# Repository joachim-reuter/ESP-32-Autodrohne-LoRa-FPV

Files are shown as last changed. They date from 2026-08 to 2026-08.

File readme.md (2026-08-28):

# ESP32 Autodrohne – LoRa-Steuerung und FPV

Ein selbstgebautes, drahtlos gesteuertes Fahrzeug auf Basis von ESP32.

Die Steuerung erfolgt über **LoRa mit 433 MHz**. Das Fahrzeug besitzt vier Antriebsmotoren, die über zwei Motorgruppen gesteuert werden. Ein Trackball im Steuerpult ermöglicht die proportionale Steuerung von Fahrtrichtung und Geschwindigkeit.

Zusätzlich ist auf dem Fahrzeug eine **FPV-Kamera** installiert. Das Kamerabild wird über eine separate **5,8-GHz-Funkverbindung** an einen FPV-Monitor übertragen, der direkt in das Steuerpult integriert ist.

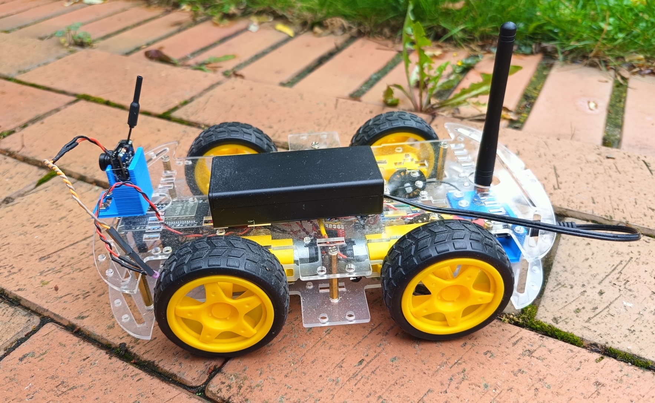
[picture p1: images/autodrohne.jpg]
Autodrohne


---

## Projektübersicht

Das System besteht aus zwei voneinander getrennten Funkverbindungen.

```text
                         STEUERPULT
┌──────────────────────────────────────────────────┐
│                                                  │
│   ESP32-Steuerung                                │
│                                                  │
│   Trackball       Drehencoder       OLED         │
│      │                │               │          │
│      └────────────────┴───────────────┘          │
│                       │                          │
│                    LoRa 433 MHz                  │
│                       │                          │
│   ┌──────────────────────────────────────────┐   │
│   │          FPV-Monitor                     │   │
│   │          5,8-GHz-Empfänger               │   │
│   └──────────────────────────────────────────┘   │
│                                                  │
└──────────────────────┬───────────────────────────┘
                       │
                       │ LoRa 433 MHz
                       │ Steuerdaten
                       ▼
              ┌──────────────────┐
              │      AUTO        │
              │                  │
              │      ESP32       │
              │      LoRa        │
              │      DRV8833     │
              │      4 Motoren   │
              │                  │
              │   FPV-Kamera     │
              └────────┬─────────┘
                       │
                       │ 5,8 GHz
                       │ Video
                       ▼
                  FPV-Empfänger
                  im Steuerpult
```

---

# Funkverbindungen

Das Fahrzeug verwendet zwei voneinander getrennte Funkstrecken.

| System | Frequenz | Funktion |
| --- | ---: | --- |
| LoRa |  433 MHz | Fahrzeugsteuerung |
| FPV |  5,8 GHz | Live-Videobild |

Die LoRa-Verbindung wird ausschließlich für die Steuerdaten und die Rückmeldung der Signalstärke verwendet.

Die FPV-Verbindung überträgt das Kamerabild unabhängig von der Fahrzeugsteuerung.

---

# Steuerung

Die Steuerung erfolgt über einen analogen Trackball.

Der Trackball ermöglicht eine proportionale Steuerung:

* Vorwärts
* Rückwärts
* Links
* Rechts

Die beiden Achsen des Trackballs werden zunächst kalibriert.

Um kleine Schwankungen um die Mittelstellung zu unterdrücken, wird eine Totzone verwendet:

```cpp
#define DEADZONE 120
```

Damit bleibt das Fahrzeug bei nicht betätigtem Trackball stehen.

---

# Geschwindigkeitsregelung

Die maximale Geschwindigkeit wird über einen Drehencoder eingestellt.

Der Einstellbereich beträgt:

```text
0–100 %
```

Der aktuelle Geschwindigkeitswert wird auf dem OLED angezeigt.

Die eigentliche Motorleistung wird anschließend auf den PWM-Bereich des Motortreibers umgesetzt.

---

# OLED-Anzeige

Im Steuerpult befindet sich ein 128 × 64 Pixel OLED.

Angezeigt werden:

* Geschwindigkeit
* Vorwärts-/Rückwärtswert
* Links-/Rechtswert
* LoRa-RSSI
* grafische Anzeige der Funkqualität

Beispiel:

```text
SPD 50%

FB: 20
LR: -10

-65 dBm       RSSI
```

Damit kann während der Fahrt sowohl die aktuelle Steuerung als auch die Qualität der LoRa-Verbindung beobachtet werden.

---

# LoRa-Steuertelegramm

Der Handsender überträgt die Steuerdaten als Texttelegramm.

Format:

```text
DRV,FB,LR,SPEED
```

Beispiel:

```text
DRV,50,-20,70
```

Bedeutung:

| Wert  | Bedeutung |
| ----- | --- |
| `DRV` | Steuertelegramm |
| `50`  | Vorwärts-/Rückwärtswert |
| `-20` | Links-/Rechtswert |
| `70`  | Geschwindigkeit 70 % |

---

# Motorsteuerung

Das Fahrzeug besitzt zwei unabhängig angesteuerte Motorgruppen.

```text
             ESP32
               │
               ▼
            DRV8833
          ┌─────┴─────┐
          │           │
          ▼           ▼
     linke Seite   rechte Seite
     2 Motoren     2 Motoren
```

Die beiden Motorgruppen werden unterschiedlich angesteuert, um das Fahrzeug zu lenken.

Die Motorwerte werden aus Fahr- und Lenkwert berechnet:

```cpp
left  = fb + lr;
right = fb - lr;
```

Die Werte werden anschließend begrenzt und entsprechend der eingestellten Geschwindigkeit auf die PWM-Ausgänge umgesetzt.

---

# Motoranschlüsse

## Linke Motorgruppe

| ESP32 | Funktion |
| --- | --- |
| GPIO 25 | PWM |
| GPIO 27 | IN1 |
| GPIO 14 | IN2 |

## Rechte Motorgruppe

| ESP32 | Funktion |
| --- | --- |
| GPIO 33 | PWM |
| GPIO 12 | IN1 |
| GPIO 13 | IN2 |

## DRV8833

| ESP32 | Funktion |
| --- | --- |
| GPIO 32 | STBY |

---

# LoRa-Anschluss

Für das LoRa-Modul werden folgende SPI-Pins verwendet:

| ESP32 | Funktion |
| --- | --- |
| GPIO 18 | SCK |
| GPIO 19 | MISO |
| GPIO 23 | MOSI |
| GPIO 5  | SS / CS  |
| GPIO 26 | DIO0 |

### Fahrzeug

Beim Fahrzeug wird kein separater Reset-Pin verwendet:

```cpp
#define LORA_RST -1
```

### Handsender

Beim Handsender wird GPIO 17 für Reset verwendet:

```cpp
#define LORA_RST 17
```

---

# ACK und RSSI

Nach dem Empfang eines gültigen Steuertelegramms sendet das Fahrzeug eine kurze Rückmeldung:

```text
ACK
```

Der Handsender empfängt diese Rückmeldung und ermittelt daraus die empfangene LoRa-Signalstärke.

Der RSSI-Wert wird anschließend auf dem OLED angezeigt.

Dadurch lässt sich die Funkverbindung während der Fahrt beobachten.

---

# Failsafe

Das Fahrzeug besitzt eine automatische Sicherheitsabschaltung.

Wenn länger als

```text
400 ms
```

kein gültiges Steuertelegramm empfangen wird, werden die Motoren gestoppt.

Zusätzlich wird der Standby-Eingang des DRV8833 deaktiviert.

```cpp
#define FAILSAFE_MS 400
```

Der Failsafe verhindert damit, dass das Fahrzeug bei einem Ausfall oder Abbruch der LoRa-Verbindung unkontrolliert weiterfährt.

---

# FPV-System

Die FPV-Kamera ist direkt auf dem Fahrzeug montiert.

Das Kamerabild wird über eine separate **5,8-GHz-Funkverbindung** übertragen.

Der zugehörige FPV-Empfänger befindet sich im Steuerpult und ist mit einem Monitor verbunden.

```text
FPV-Kamera
     │
     │ 5,8 GHz
     ▼
FPV-Empfänger
     │
     ▼
Monitor im Steuerpult
```

Dadurch kann das Fahrzeug über das Livebild der Kamera gesteuert werden.

Die FPV-Übertragung ist unabhängig von der LoRa-Steuerung.

---

# Steuerpult

Das Steuerpult vereint die komplette Bedienung:

* ESP32
* LoRa-Sender
* Trackball
* Drehencoder
* OLED
* 5,8-GHz-FPV-Empfänger
* FPV-Monitor

Damit befinden sich Fahrzeugsteuerung und Kamerabild in einer gemeinsamen Bedieneinheit.

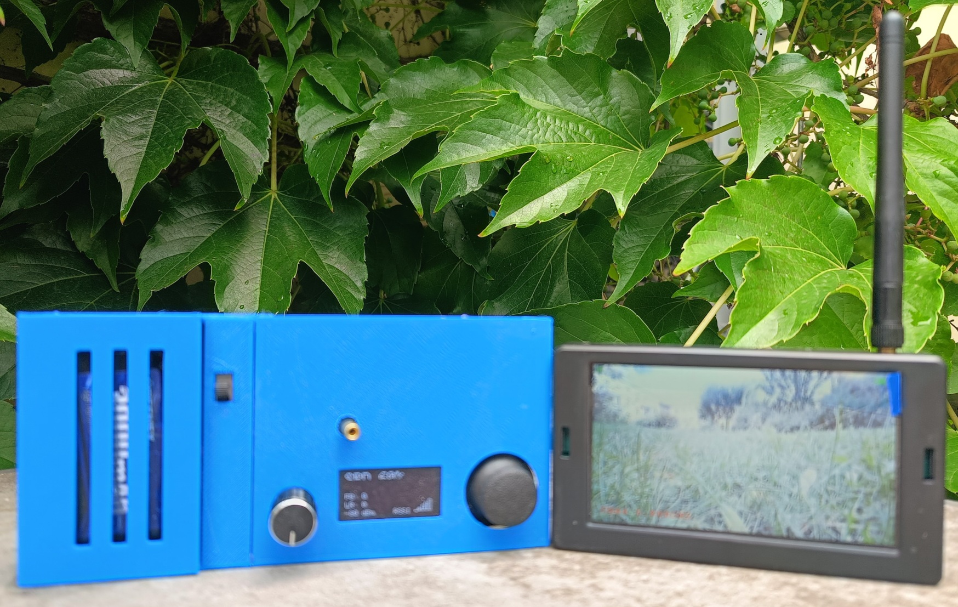
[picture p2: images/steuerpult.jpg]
Steuerpult


---

# Hardware

## Fahrzeug

* ESP32
* LoRa-Modul
* DRV8833
* 4 Gleichstrommotoren
* FPV-Kamera
* 5,8-GHz-Videosender
* Fahrzeugakku

## Steuerpult

* ESP32
* LoRa-Modul
* analoger Trackball
* Drehencoder
* 128 × 64 OLED
* 5,8-GHz-FPV-Empfänger
* FPV-Monitor

---

# Handsender – Anschlüsse

## Trackball

| ESP32 | Funktion |
| --- | --- |
| GPIO 34 | X-Achse  |
| GPIO 35 | Y-Achse  |

## Drehencoder

| ESP32 | Funktion |
| --- | --- |
| GPIO 27 | CLK |
| GPIO 14 | DT |
| GPIO 32 | Taster |

## OLED

Das OLED wird über I²C angeschlossen:

| ESP32 | Funktion |
| --- | --- |
| GPIO 21 | SDA |
| GPIO 22 | SCL |

I²C-Adresse:

```text
0x3C
```

---

# Software

## Fahrzeug

Der Fahrzeug-Empfänger verwendet:

```cpp
#include <SPI.h>
#include <LoRa.h>
```

## Handsender

Der Handsender verwendet:

```cpp
#include <SPI.h>
#include <LoRa.h>
#include <Wire.h>
#include <Adafruit_GFX.h>
#include <Adafruit_SH110X.h>
```

---

# Dateien

Das Repository enthält die beiden Hauptbereiche:

```text
ESP32-Autodrohne-LoRa-FPV/
│
├── README.md
│
├── _AutoDrohne_Empfaenger.ino
├── _AutoDrohne_Sender.ino
│
└── images/
    ├── autodrohne.jpg
    └── steuerpult.jpg
```

Die Dateinamen können entsprechend den tatsächlich im Repository verwendeten Namen angepasst werden.

---

# Systemaufbau

```text
┌──────────────────────┐
│      STEUERPULT      │
│                      │
│ ESP32                │
│ Trackball            │
│ Drehencoder          │
│ OLED                 │
│ LoRa                 │
│ FPV Monitor          │
│ 5,8 GHz Empfänger    │
└──────────┬───────────┘
           │
           │ 433 MHz
           │ Steuerdaten
           ▼
┌──────────────────────┐
│        AUTO          │
│                      │
│ ESP32                │
│ LoRa                 │
│ DRV8833              │
│ 4 Motoren            │
│ FPV Kamera           │
│ 5,8 GHz Sender       │
└──────────────────────┘
```

---

# Projektstatus

Das Projekt befindet sich in Entwicklung.

Die LoRa-Fahrzeugsteuerung mit:

* Trackball
* Geschwindigkeitsregelung
* OLED-Anzeige
* RSSI-Anzeige
* ACK-Rückmeldung
* Failsafe
* Zweimotorgruppensteuerung

ist als funktionierender Entwicklungsstand vorhanden.

Die FPV-Kamera und die 5,8-GHz-Videoübertragung sind als separates Videosystem in das Fahrzeug und das Steuerpult integriert.

---

# Mögliche Erweiterungen

Das System bietet verschiedene Möglichkeiten zur Erweiterung:

* Akkuspannungsanzeige
* Telemetrie
* Entfernungsmessung
* weitere Sensoren
* Beleuchtung
* Bremslicht
* Hupe/Sound
* Kameraschwenkung
* zusätzliche FPV-Funktionen
* weitere Fahrzeugfunktionen
* Verbesserung der Reichweiten- und Signalüberwachung

---

# Autor

**Joachim Reuter**

Privates ESP32-, LoRa-, FPV- und Modellbauprojekt.

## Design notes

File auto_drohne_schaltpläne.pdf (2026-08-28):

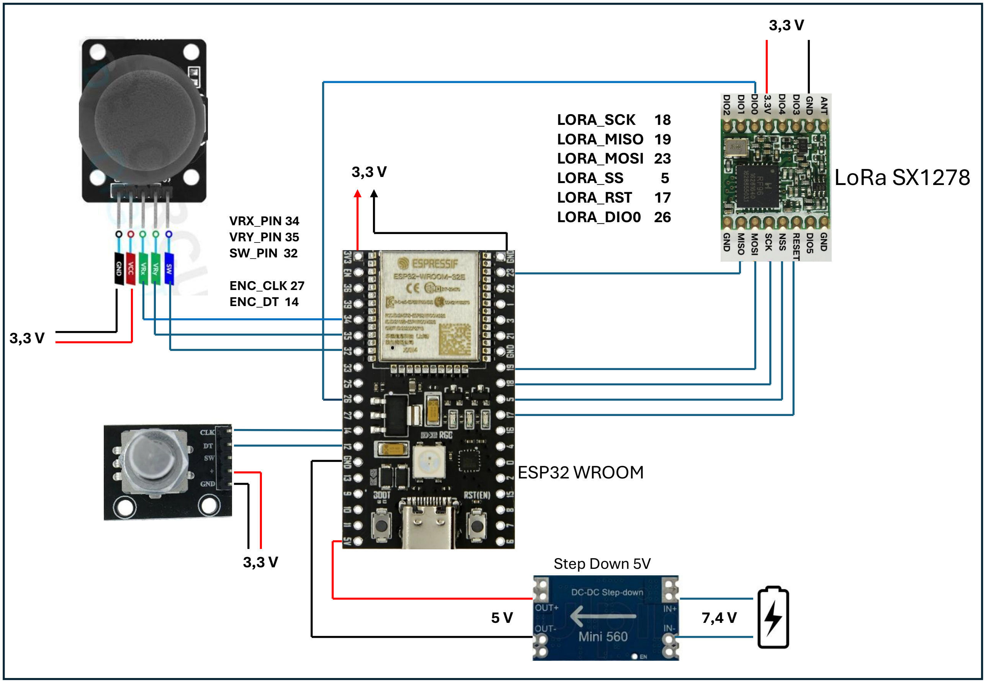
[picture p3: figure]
LORA_SCK 18 LORA_MISO 19 LORA_MOSI 23; LORA_SS; LORA_RST 17 LORA_DIO0 26; ESP32 WROOM; LoRa SX1278; VRX_PIN 34 VRY_PIN 35 SW_PIN 32; ENC_CLK 27 ENC_DT 14; Step Down 5V

3,3 V

LORA_SCK 18
LORA_MISO 19
LORA_MOSI 23
LORA_SS 5
LORA_RST 17
LORA_DIO0 26

## ESP32 WROOM

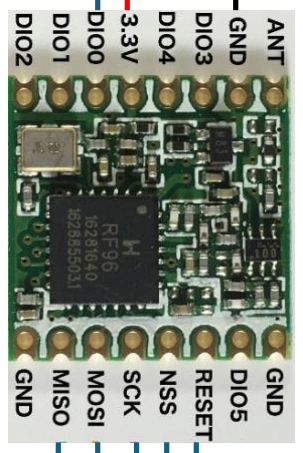
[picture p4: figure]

## LoRa SX1278

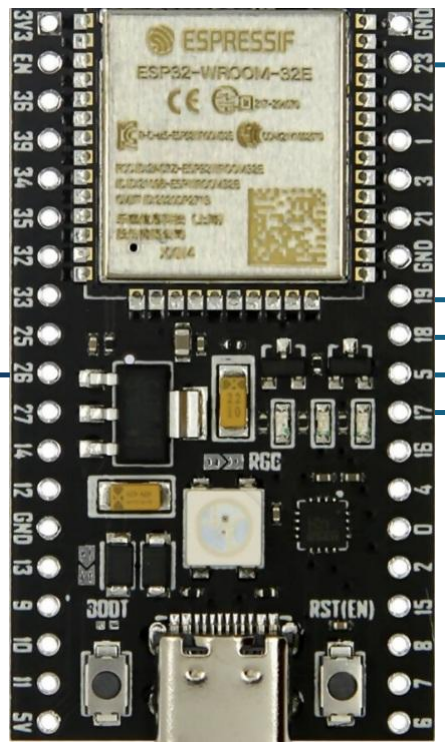
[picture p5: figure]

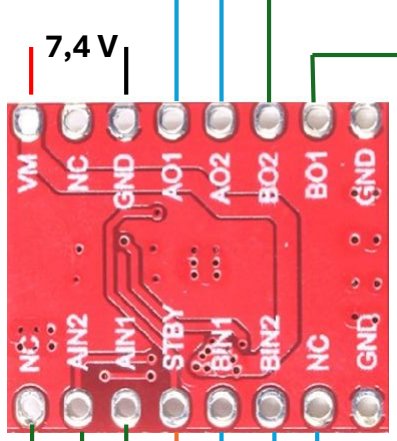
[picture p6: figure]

## DRV8833

## ESP32 WROOM

Antriebsmotoren links

M1_PWM 25
M1_IN1 27
M1_IN2 14

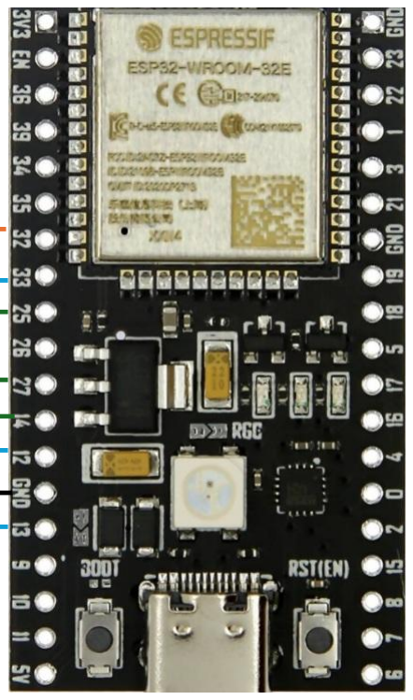
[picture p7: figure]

M2_PWM 33
M2_IN1 12
M2_IN2 13

DRV_STBY 32

Antriebsmotoren rechts

Step Down 5V

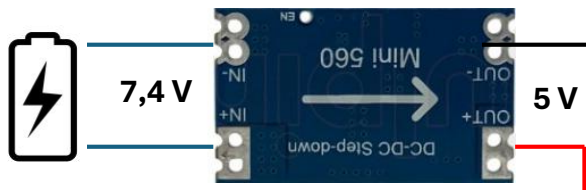
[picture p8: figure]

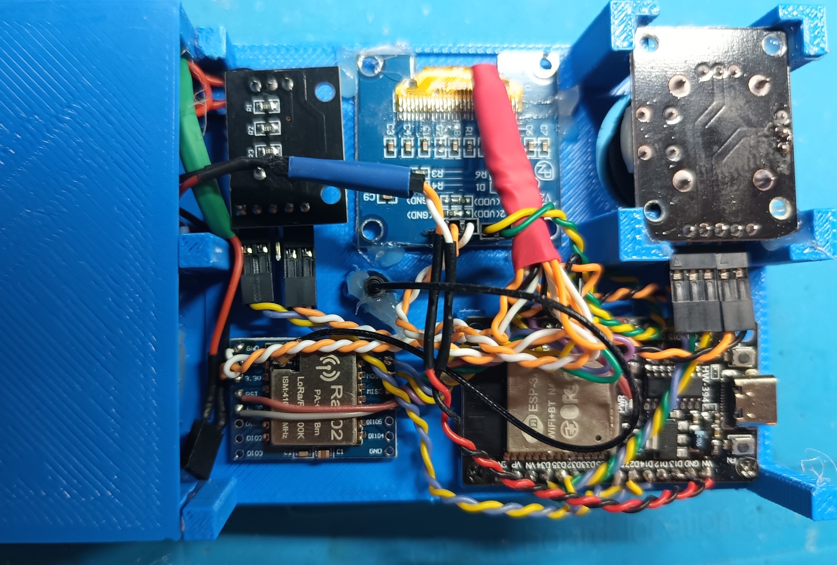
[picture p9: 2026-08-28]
images/pult_innen.jpg

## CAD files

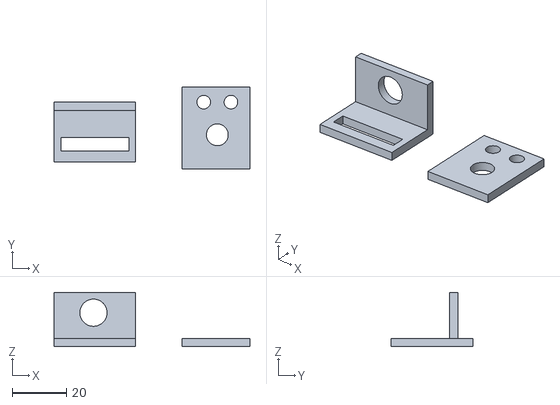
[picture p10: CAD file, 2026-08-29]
3D_print/Auto_Kabel_V1.stl
72.0 x 30.0 x 20.0

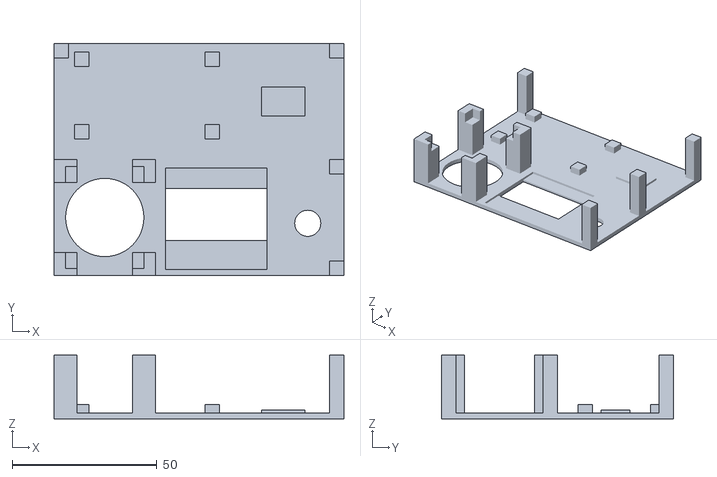
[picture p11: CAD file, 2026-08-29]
3D_print/Auto_Gehäuse_V2.stl
100.0 x 80.0 x 22.0

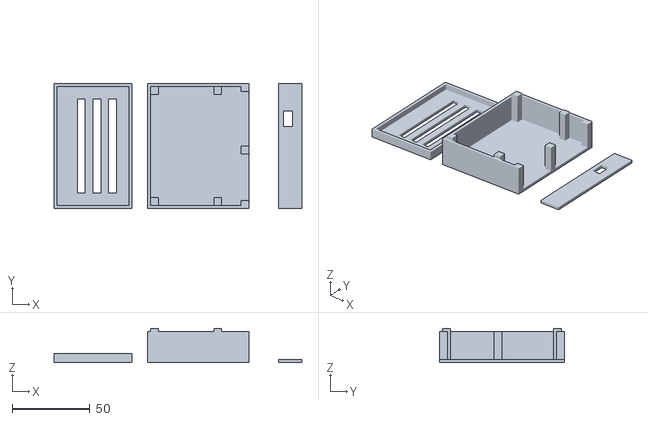
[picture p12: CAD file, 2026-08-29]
3D_print/Auto_Akku_Halter_V1.stl
159.0 x 80.0 x 22.0

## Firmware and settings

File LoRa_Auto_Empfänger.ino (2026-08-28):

#include <SPI.h>
#include <LoRa.h>

// ================= LoRa =================
#define LORA_SCK   18
#define LORA_MISO  19
#define LORA_MOSI  23
#define LORA_SS     5
#define LORA_RST   -1
#define LORA_DIO0  26

// ================= DRV8833 =================
// Linke Seite (2 Motoren parallel)
#define M1_PWM 25
#define M1_IN1 27
#define M1_IN2 14

// Rechte Seite (2 Motoren parallel)
#define M2_PWM 33
#define M2_IN1 12
#define M2_IN2 13

#define DRV_STBY 32

// ================= Failsafe =================
unsigned long lastPacket = 0;
const unsigned long FAILSAFE_MS = 400;

// ================= Motor =================
void setMotor(int pwmPin, int in1, int in2, int value) {
  value = constrain(value, -255, 255);

  if (value > 0) {
    digitalWrite(in1, HIGH);
    digitalWrite(in2, LOW);
    analogWrite(pwmPin, value);
  }
  else if (value < 0) {
    digitalWrite(in1, LOW);
    digitalWrite(in2, HIGH);
    analogWrite(pwmPin, -value);
  }
  else {
    digitalWrite(in1, LOW);
    digitalWrite(in2, LOW);
    analogWrite(pwmPin, 0);
  }
}

void stopMotors() {
  analogWrite(M1_PWM, 0);
  analogWrite(M2_PWM, 0);

  digitalWrite(M1_IN1, LOW);
  digitalWrite(M1_IN2, LOW);
  digitalWrite(M2_IN1, LOW);
  digitalWrite(M2_IN2, LOW);
}

// ================= Setup =================
void setup() {
  Serial.begin(115200);
  Serial.println("🚗 LoRa EMPFÄNGER gestartet");

  pinMode(M1_PWM, OUTPUT);
  pinMode(M1_IN1, OUTPUT);
  pinMode(M1_IN2, OUTPUT);

  pinMode(M2_PWM, OUTPUT);
  pinMode(M2_IN1, OUTPUT);
  pinMode(M2_IN2, OUTPUT);

  pinMode(DRV_STBY, OUTPUT);
  digitalWrite(DRV_STBY, HIGH);

  stopMotors();

  SPI.begin(LORA_SCK, LORA_MISO, LORA_MOSI, LORA_SS);
  LoRa.setPins(LORA_SS, LORA_RST, LORA_DIO0);

  if (!LoRa.begin(433E6)) {
    Serial.println("❌ LoRa Fehler");
    while (1);
  }

  Serial.println("✅ LoRa bereit");
}

// ================= Loop =================
void loop() {
  int packetSize = LoRa.parsePacket();

  if (packetSize) {
    String msg = LoRa.readString();
    msg.trim();
    lastPacket = millis();

    int fb, lr, speed;
    if (sscanf(msg.c_str(), "DRV,%d,%d,%d", &fb, &lr, &speed) == 3) {

      // --- Mischen ---
      int left  = fb + lr;
      int right = fb - lr;

      left  = constrain(left,  -100, 100);
      right = constrain(right, -100, 100);

      int maxPWM = map(speed, 0, 100, 0, 255);

      left  = left  * maxPWM / 100;
      right = right * maxPWM / 100;

      setMotor(M1_PWM, M1_IN1, M1_IN2, left);
      setMotor(M2_PWM, M2_IN1, M2_IN2, right);

      // ACK (optional für RSSI)
      LoRa.beginPacket();
      LoRa.print("ACK");
      LoRa.endPacket();
    }
  }

  // ================= Failsafe =================
  if (millis() - lastPacket > FAILSAFE_MS) {
    stopMotors();
    digitalWrite(DRV_STBY, LOW);
  } else {
    digitalWrite(DRV_STBY, HIGH);
  }
}

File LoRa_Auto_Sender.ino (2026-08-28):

#include <SPI.h>
#include <LoRa.h>
#include <Wire.h>
#include <Adafruit_GFX.h>
#include <Adafruit_SH110X.h>

// ========== OLED ==========
Adafruit_SH1106G display(128, 64, &Wire, -1);

// ========== Trackball ==========
#define VRX_PIN 34
#define VRY_PIN 35

// ========== Encoder ==========
#define ENC_CLK 27
#define ENC_DT  14
#define ENC_SW  32

volatile int speed = 50;
portMUX_TYPE mux = portMUX_INITIALIZER_UNLOCKED;

// ========== LoRa ==========
#define LORA_SCK   18
#define LORA_MISO  19
#define LORA_MOSI  23
#define LORA_SS     5
#define LORA_RST   17
#define LORA_DIO0  26

int lastRSSI = -120;

// ========== Trackball Kalibrierung ==========
int xCenter = 0;
int yCenter = 0;
#define DEADZONE 120

// ---------- Encoder ISR ----------
void IRAM_ATTR encoderISR() {
  portENTER_CRITICAL_ISR(&mux);
  if (digitalRead(ENC_DT)) speed++;
  else speed--;
  speed = constrain(speed, 0, 100);
  portEXIT_CRITICAL_ISR(&mux);
}

// ---------- Trackball Mapping ----------
int mapAxis(int raw, int center) {
  if (abs(raw - center) < DEADZONE) return 0;

  if (raw > center) {
    return map(raw, center + DEADZONE, 4095, 0, 100);
  } else {
    return map(raw, 0, center - DEADZONE, -100, 0);
  }
}

// ---------- Kalibrierung ----------
void calibrateCenter() {
  long sx = 0, sy = 0;
  for (int i = 0; i < 50; i++) {
    sx += analogRead(VRX_PIN);
    sy += analogRead(VRY_PIN);
    delay(5);
  }
  xCenter = sx / 50;
  yCenter = sy / 50;
}

// ---------- RSSI Balken ----------
void drawRSSIBar(int rssi) {
  int bars = map(rssi, -120, -40, 0, 5);
  bars = constrain(bars, 0, 5);

  display.setCursor(70, 54);
  display.print("RSSI");

  for (int i = 0; i < 5; i++) {
    if (i < bars)
      display.fillRect(100 + i * 5, 58 - i * 4, 4, i * 4, SH110X_WHITE);
    else
      display.drawRect(100 + i * 5, 58 - i * 4, 4, i * 4, SH110X_WHITE);
  }
}

// ---------- OLED ----------
void drawOLED(int fb, int lr) {
  display.clearDisplay();

  display.setTextSize(2);
  display.setCursor(0, 0);
  display.print("SPD ");
  display.print(speed);
  display.print("%");

  display.setTextSize(1);
  display.setCursor(0, 30);
  display.print("FB: ");
  display.print(fb);

  display.setCursor(0, 42);
  display.print("LR: ");
  display.print(lr);

  display.setCursor(0, 54);
  display.print(lastRSSI);
  display.print(" dBm");

  drawRSSIBar(lastRSSI);
  display.display();
}

// ---------- Setup ----------
void setup() {
  Serial.begin(115200);

  pinMode(ENC_CLK, INPUT_PULLUP);
  pinMode(ENC_DT, INPUT_PULLUP);
  pinMode(ENC_SW, INPUT_PULLUP);
  attachInterrupt(digitalPinToInterrupt(ENC_CLK), encoderISR, FALLING);

  Wire.begin(21, 22);
  display.begin(0x3C, true);
  display.setTextColor(SH110X_WHITE);

  // Trackball Kalibrieren (NICHT anfassen!)
  delay(1000);
  calibrateCenter();

  SPI.begin(LORA_SCK, LORA_MISO, LORA_MOSI, LORA_SS);
  LoRa.setPins(LORA_SS, LORA_RST, LORA_DIO0);
  LoRa.begin(433E6);
}

// ---------- Loop ----------
void loop() {
  int rawX = analogRead(VRX_PIN);
  int rawY = analogRead(VRY_PIN);

  int lr = mapAxis(rawX, xCenter);
  int fb = -mapAxis(rawY, yCenter);

  String msg = "DRV," + String(fb) + "," + String(lr) + "," + String(speed);

  LoRa.beginPacket();
  LoRa.print(msg);
  LoRa.endPacket();

  // ---- ACK / RSSI ----
  unsigned long t0 = millis();
  while (millis() - t0 < 30) {
    int p = LoRa.parsePacket();
    if (p) {
      String r = LoRa.readString();
      if (r.startsWith("ACK")) {
        lastRSSI = LoRa.packetRssi();
      }
    }
  }

  drawOLED(fb, lr);
  delay(40);
}
